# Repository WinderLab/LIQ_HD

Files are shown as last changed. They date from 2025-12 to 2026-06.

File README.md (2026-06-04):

# LIQ-HD - Lick Instance Quantifier Home cage Device 

## UPDATE: 1/19/2024 (Arduino Mega version only)

We have now included the ability to log the lick data by individual bouts! With this setting turned on, each individual bout will be logged with a line in the file with the side the experimental bottle is on (LEFT or RIGHT), a time stamp, the cage number, which bottle was licked (LEFT or RIGHT), bout lick number, bout lick duration, average lick frequency of that bout, and average inter-lick interval of that bout. Note, this setting will not log the total lick number and lick duration (i.e. licks that do not meet bout criteria).

The "log by bout" setting can be turned on using the GUI under "Parameters to log". This setting can be made the default by changing the Arduino code lines 186-187. For example:

bool log_by_bout = true; bool log_by_time = false; //will set the default to "log by bout".

bool log_by_bout = false; bool log_by_time = true; //will set the default to "log by time" (original logging method).

We have also made it easier to change the bout cutoff time (the amount of time during a drinking bout where an animal stops licking before the bout is considered over) by changing the "bout_cutoff" variable on line 185.

We made some minor changes to the capacitive sensor settings that optimizes the baseline tracking for more consistent lick detection.

----------------------------

### Included in this repository:

- Arduino code for LIQ HD running off an Arduino Mega
- Arduino code for LIQ HD running off an Adafruit Grand Central (significantly faster processor speed. NOT FULLY TESTED.)
- 3D models for all required 3D-printed components in various file formats (STL, STEP, SHAPR)
- Step-by-step build instructions and video tutorial can be found on the [Wiki page](https://github.com/WinderLab/LIQ_HD/wiki/LIQ-HD-Step-by-Step-Tutorial)

----------------------------

### Required Arduino Libraries:

- Adafruit_GFX.h
- RTClib.h
- SdFat.h
- Adafruit_MPR121.h
- Adafruit_ILI9341.h
- Adafruit_FT6206.h

---------------------------

### Publication Link : https://www.eneuro.org/content/10/4/ENEURO.0506-22.2023

## Abstract

Investigation of rodent drinking behavior has provided insight into drivers of thirst, circadian rhythms, anhedonia, and drug and ethanol consumption. Traditional methods of recording fluid intake involve periodically weighing bottles, 
which is cumbersome and lacks temporal resolution. Several open-source devices have been designed to improve drink monitoring, particularly for two-bottle choice tasks. However, recent designs are limited by the use of infrared 
photobeam-break sensors and incompatibility with prolonged undisturbed use in ventilated home cages. Beam-break sensors lack accuracy for bout microstructure analysis and are prone to damage from rodents. To address these concerns, we 
designed LIQ HD (Lick Instance Quantifier Home cage Device) with the goal of utilizing capacitive sensors to increase accuracy and analyze lick microstructure, building a device compatible with ventilated vivarium home cages, increasing 
scale with prolonged undisturbed recordings, and creating a design that is easy to build and use with an intuitive touchscreen graphical user interface. The system tracks two-bottle choice licking behavior in up to 18 rodent home cages, 
or 36 single bottles, on a minute-to-minute timescale controlled by a single Arduino microcontroller. The data are logged to a single SD card, allowing for efficient downstream analysis. With sucrose, quinine, and ethanol two-bottle choice 
tasks, we validated that LIQ HD has superior accuracy compared to beam-break sensors. The system measures preference over time and changes in bout microstructure, with undisturbed recordings lasting up to 7 days. All designs and software 
are open-source to allow other researchers to build upon the system and adapt LIQ HD to their animal home cages.

207975271-d024acc4-405c-4381-a1c6-2fc56d0128fb

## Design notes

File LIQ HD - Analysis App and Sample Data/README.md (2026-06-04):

# LIQ HD Analysis 

<p align="center">
LIQ HD Analysis App
</p>

## Included in this folder:
  - LIQ HD Analysis 1.0 Installer for MacOS and Windows
  - Sample LIQ HD Data
    - "LIQ_HD_Sample_Data_Water.CSV" contains data from 16 cages of water two-bottle choice for 1 week. Cages 17 & 18 are empty.
    - "LIQ_HD_Sample_Data_EtOH_Sucrose.CSV" contains data from 8 cages of ethanol two-bottle choice (Cages 1 to 8 - 7% EtOH versus water), and 8 cages of sucrose two-bottle choice (Cages 9 to 16 - 1% Sucrose versus water) for 1 week. Cages 17 & 18 are empty.
  - A How-To Guide can be found on the [Wiki page](https://github.com/WinderLab/LIQ_HD/wiki/LIQ-HD-Analysis-App-Guide) (Coming soon!)

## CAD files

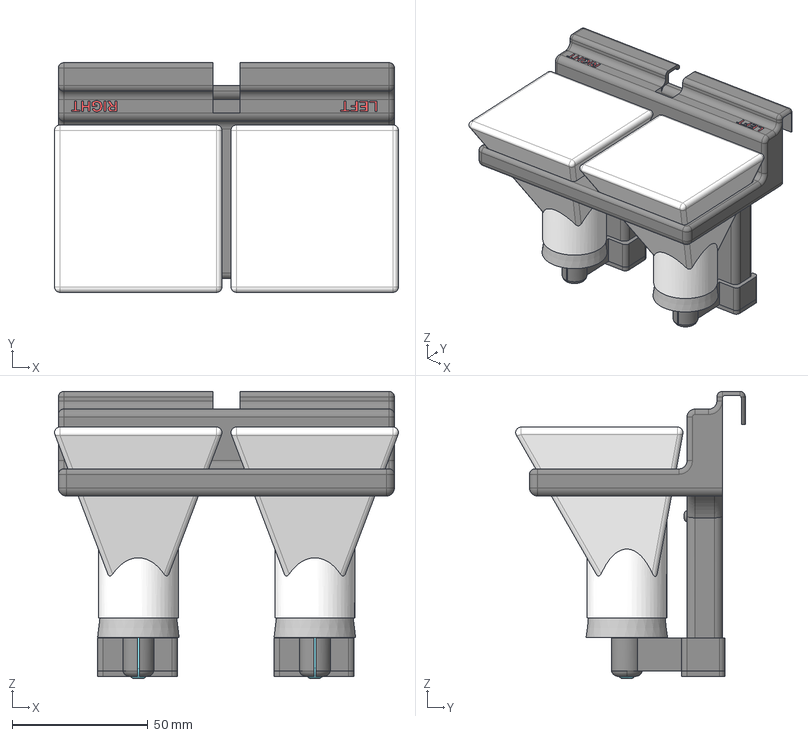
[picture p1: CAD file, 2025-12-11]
LIQ HD - 3D Models github/STEP/LIQ HD - Full model.step
126.5 x 84.5 x 105.6 mm
spouts
stoppers
clips
Text - LEFT/RIGHT
bottles

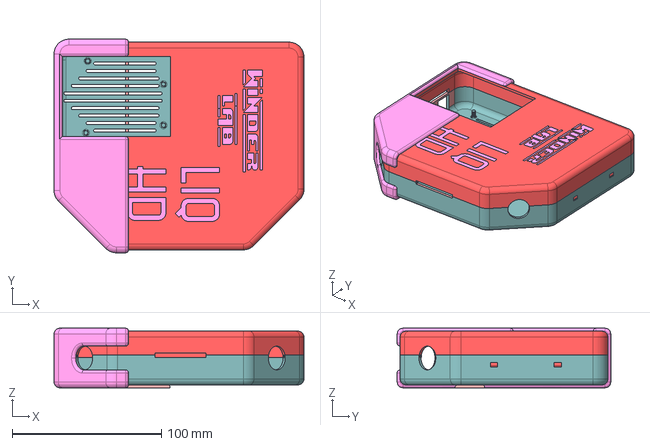
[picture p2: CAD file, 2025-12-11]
LIQ HD - 3D Models github/STEP/LIQ HD - Arduino Box.step
167.8 x 143.4 x 40.0 mm

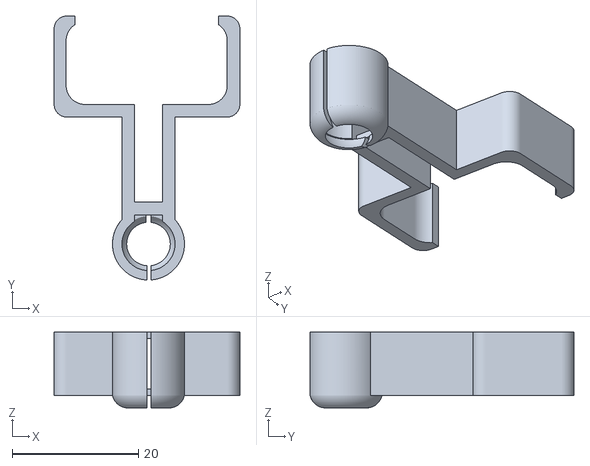
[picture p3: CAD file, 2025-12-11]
LIQ HD - 3D Models github/STL/LIQ HD - Device CLIP 10mm.stl
29.4 x 41.8 x 12.0

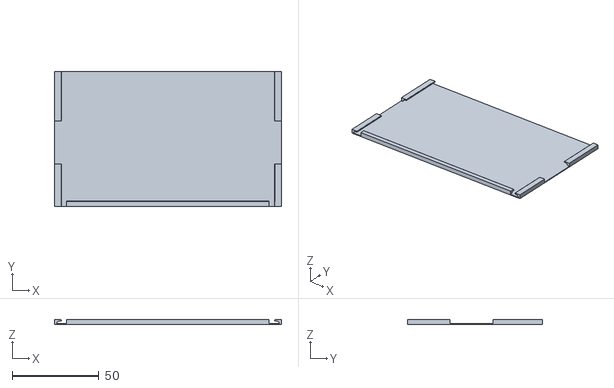
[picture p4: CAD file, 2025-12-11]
LIQ HD - 3D Models github/STL/LIQ HD Card Holder.stl
131.0 x 78.0 x 2.80

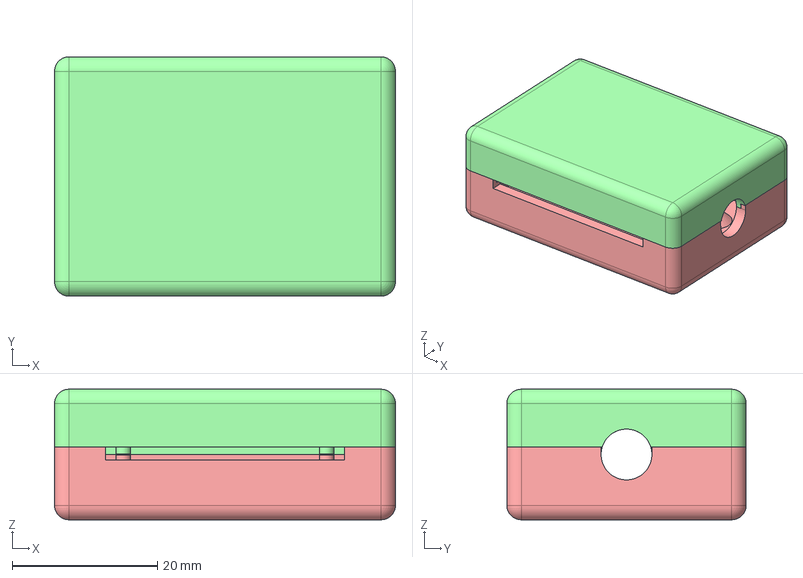
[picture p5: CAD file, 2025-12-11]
LIQ HD - 3D Models github/STEP/LIQ HD - Sensor Box.step
47.0 x 33.0 x 18.0 mm

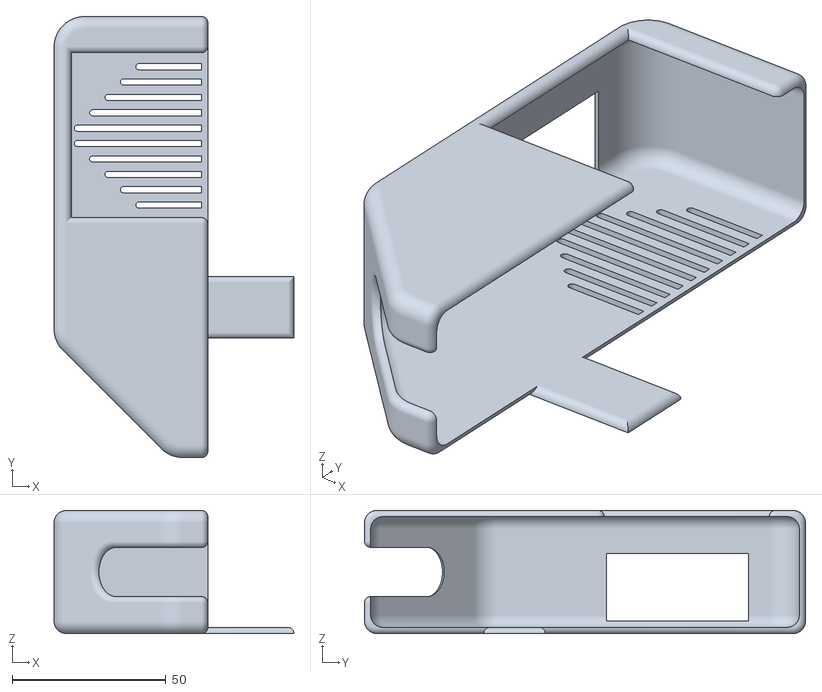
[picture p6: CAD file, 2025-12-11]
LIQ HD - 3D Models github/STL/LIQ HD - Arduino box HOLDER.stl
78.0 x 143.4 x 40.0

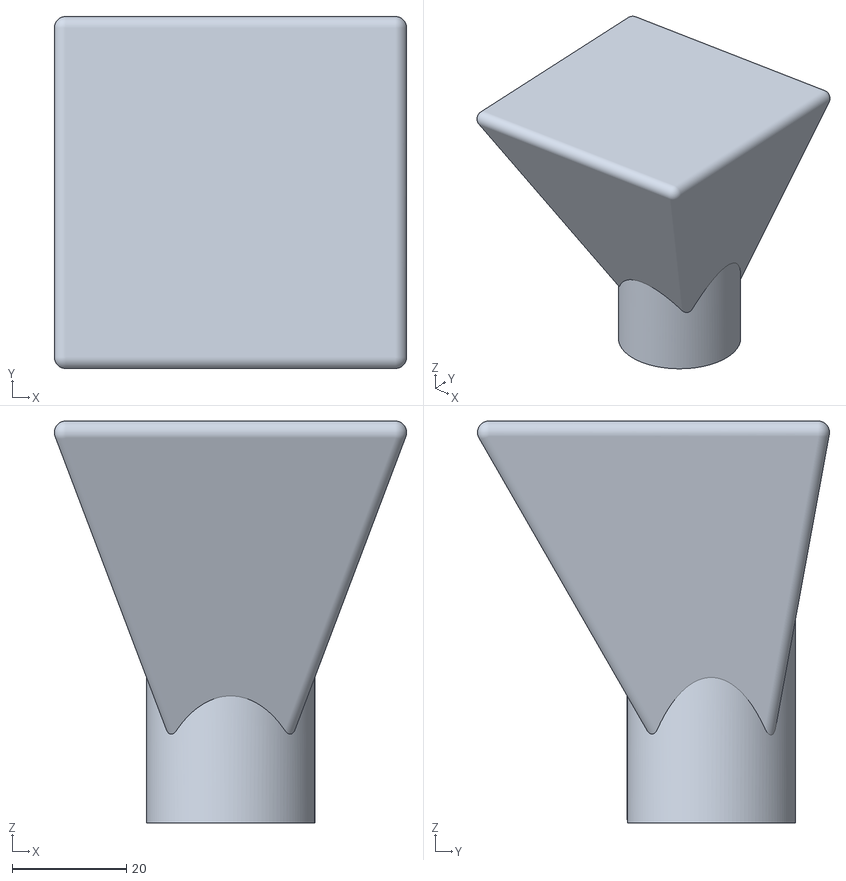
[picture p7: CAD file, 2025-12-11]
LIQ HD - 3D Models github/STL/LIQ HD - Bottle 27mm opening.stl
61.6 x 61.5 x 70.3

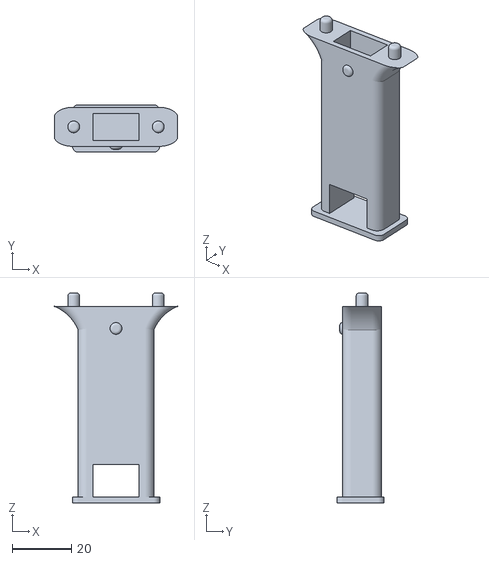
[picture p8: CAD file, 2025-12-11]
LIQ HD - 3D Models github/STL/LIQ HD - Device LEG .stl
41.5 x 16.0 x 70.8

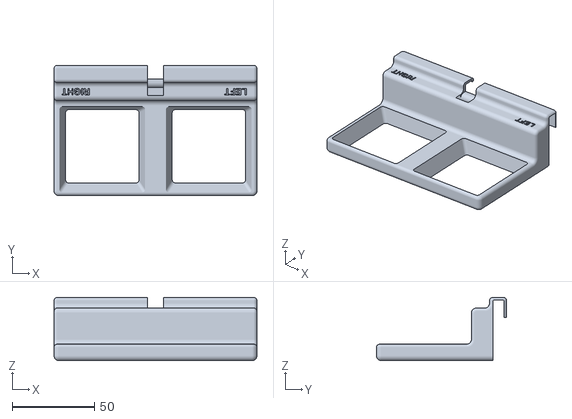
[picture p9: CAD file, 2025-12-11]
LIQ HD - 3D Models github/STL/LIQ HD - Device TOP.stl
123.6 x 79.4 x 38.5

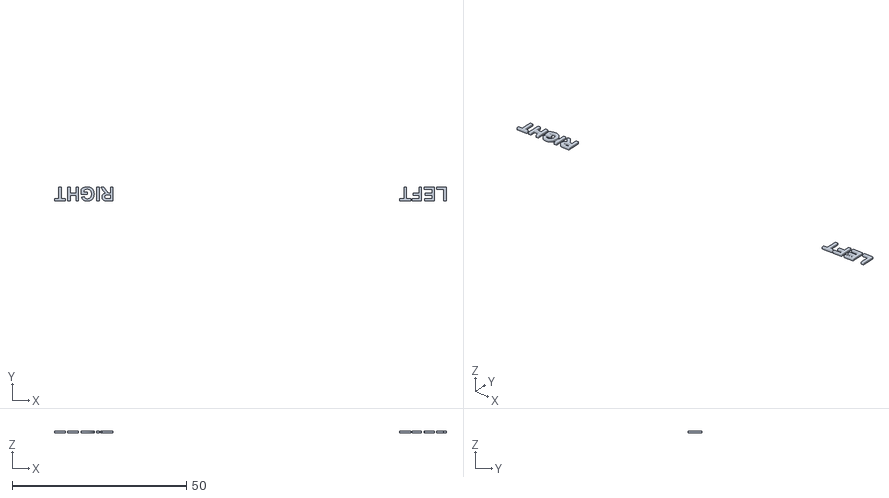
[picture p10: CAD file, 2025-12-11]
LIQ HD - 3D Models github/STL/LIQ HD - Device TEXT.stl
112.5 x 4.14 x 0.6

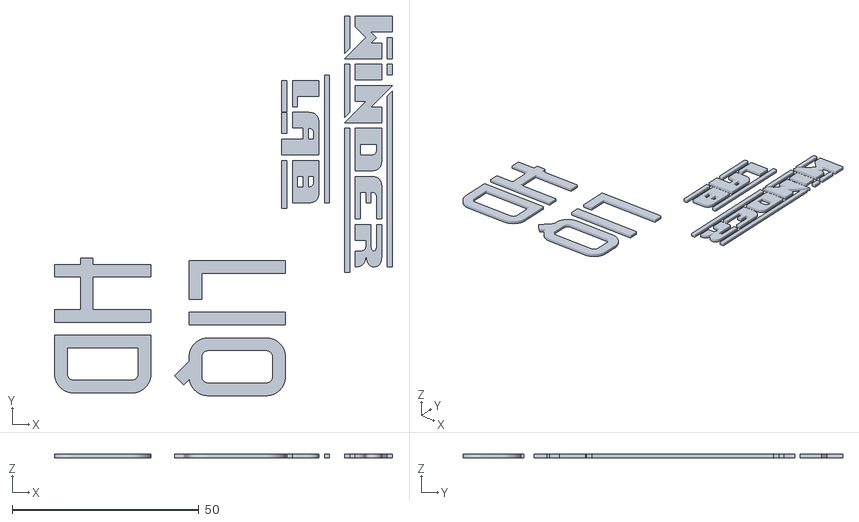
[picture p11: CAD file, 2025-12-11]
LIQ HD - 3D Models github/STL/LIQ HD - Arduino box TEXT.stl
90.5 x 101.6 x 1.00

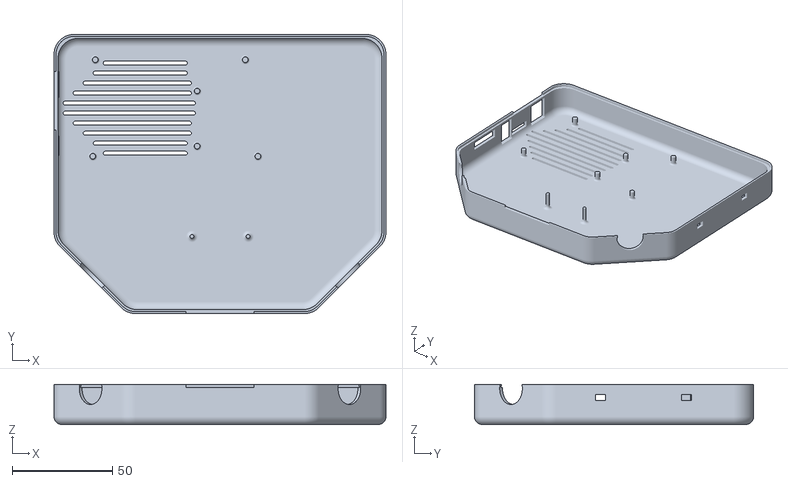
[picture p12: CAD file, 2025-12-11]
LIQ HD - 3D Models github/STL/LIQ HD - Arduino box BOTTOM.stl
165.8 x 139.4 x 20.0

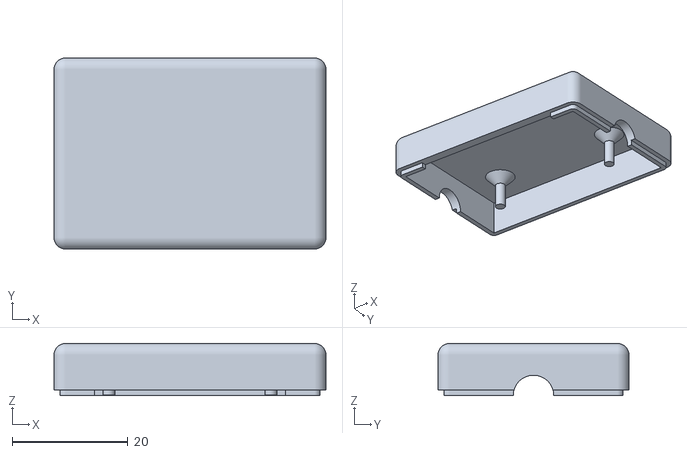
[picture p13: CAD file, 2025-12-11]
LIQ HD - 3D Models github/STL/LIQ HD - Sensor case TOP.stl
47.0 x 33.0 x 9.00

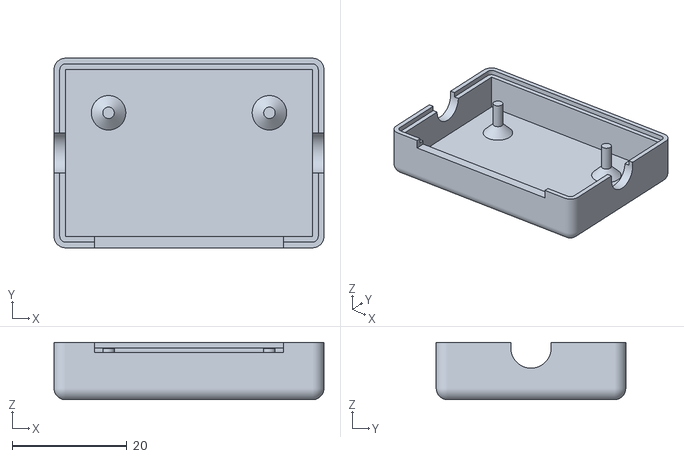
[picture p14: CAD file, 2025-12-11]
LIQ HD - 3D Models github/STL/LIQ HD - Sensor case BOTTOM.stl
47.0 x 33.0 x 10.0

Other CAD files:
LIQ HD - 3D Models github/STL/LIQ HD - Arduino box TOP.stl

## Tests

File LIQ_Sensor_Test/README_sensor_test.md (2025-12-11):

Upload this script to your LIQ HD system and open the serial plotter on the Arduino IDE to visually test lick threshold settings! It is recomended to test only 2-4 sensors because the serial plotter begins to run slowly. If the serial plotter is running too quickly to visualize detected licks, you can slow it down by adding a delay (change "delay_time"). Run this test on a fully built LIQ system in its experimental environment because certain changes, such as wire length, will affect the necessary threshold settings.

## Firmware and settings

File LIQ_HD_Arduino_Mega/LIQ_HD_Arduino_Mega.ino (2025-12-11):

/********************************************************
  LIQ HD
  Written by Nicholas Petersen
  https://github.com/nickpetersen93/LIQ_HD

  January, 2023

  This work includes libraries with the following licensing:
  Adafruit GFX Library - Written by Limor Fried/Ladyada for Adafruit Industries. BSD License
  Adafruit ILI9341 Library - Written by Limor Fried/Ladyada for Adafruit Industries. MIT license. BSD License.
  Adafruit FT6206 Library - Written by Limor Fried/Ladyada for Adafruit Industries. MIT license.
  Adafruit MPR121 Library - Written by Limor Fried/Ladyada for Adafruit Industries. MIT license. BSD License.
  RTCLib Library - Written by JeeLabs. MIT license.
    
  This work is released under This work is licensed under a Creative Commons Attribution-NonCommercial-ShareAlike 4.0 International License:
  https://creativecommons.org/licenses/by-nc-sa/4.0/legalcode

  Copyright (c) 2023 Nicholas Petersen. Creative Commons BY-NC-SA License. Non-Commercial Use Only. 
  Adapter’s License must be a Creative Commons BY-NC-SA or Compatible License. 
  All text above must be included in any redistribution. See LICENSE.md for detailed information.

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
  TO THE EXTENT POSSIBLE, IN NO EVENT WILL THE LICENSOR BE LIABLE TO YOU ON ANY LEGAL THEORY (INCLUDING, 
  WITHOUT LIMITATION, NEGLIGENCE) OR OTHERWISE FOR ANY DIRECT, SPECIAL, INDIRECT, INCIDENTAL, 
  CONSEQUENTIAL, PUNITIVE, EXEMPLARY, OR OTHER LOSSES, COSTS, EXPENSES, OR DAMAGES ARISING OUT OF THIS 
  PUBLIC LICENSE OR USE OF THE LICENSED MATERIAL, EVEN IF THE LICENSOR HAS BEEN ADVISED OF THE 
  POSSIBILITY OF SUCH LOSSES, COSTS, EXPENSES, OR DAMAGES. WHERE A LIMITATION OF LIABILITY IS NOT 
  ALLOWED IN FULL OR IN PART, THIS LIMITATION MAY NOT APPLY TO YOU.
  
  THE DISCLAIMER OF WARRANTIES AND LIMITATION OF LIABILITY PROVIDED ABOVE SHALL BE INTERPRETED IN A 
  MANNER THAT, TO THE EXTENT POSSIBLE, MOST CLOSELY APPROXIMATES AN ABSOLUTE DISCLAIMER AND WAIVER OF 
  ALL LIABILITY.


********************************************************/

#include <Adafruit_GFX.h>
#include <SPI.h>
#include <Wire.h>
#include <SD.h>
#include "RTClib.h"
#include "Adafruit_MPR121.h"
#include <Adafruit_ILI9341.h>
#include <Adafruit_FT6206.h>
#include <math.h>
#include <Fonts/FreeSans9pt7b.h>
#include <Fonts/FreeSans12pt7b.h>
#include <Fonts/FreeSans18pt7b.h>
#include <Fonts/FreeSansBold9pt7b.h>
#include <Fonts/FreeSansBold12pt7b.h>
#include <Fonts/FreeSansBold18pt7b.h>
#include <Fonts/FreeSansBold24pt7b.h>


//#define DEBUG //uncomment to turn on debug mode, prints info to Serial Monitor

#ifdef DEBUG
#define DEBUG_PRINT(x) Serial.print(x)
#define DEBUG_PRINTDEC(x) Serial.print(x, DEC)
#define DEBUG_PRINTLN(x) Serial.println(x)
#else
#define DEBUG_PRINT(x)
#define DEBUG_PRINTDEC(x)
#define DEBUG_PRINTLN(x)
#endif

// The FT6206 uses hardware I2C on the shield
Adafruit_FT6206 ts = Adafruit_FT6206();

// The display also uses hardware SPI, plus #9 & #10
#define TFT_CS 10
#define TFT_DC 9
Adafruit_ILI9341 tft = Adafruit_ILI9341(TFT_CS, TFT_DC);

RTC_PCF8523 rtc;           // define the Real Time Clock object
const int chipSelect = 7;  // for the data logging shield, changed from digital pin 10
#define redLEDpin 13
DateTime now;

//capacitive touch device
#ifndef _BV
#define _BV(bit) (1 << (bit))
#endif

// You can have up to 4 on one i2c bus but one is enough for testing!
Adafruit_MPR121 cap = Adafruit_MPR121();
Adafruit_MPR121 cap2 = Adafruit_MPR121();
Adafruit_MPR121 cap3 = Adafruit_MPR121();

// Keeps track of the last pins touched so we know when buttons are 'released'
uint16_t lasttouched1 = 0;
uint16_t currtouched1 = 0;
uint16_t lasttouched2 = 0;
uint16_t currtouched2 = 0;
uint16_t lasttouched3 = 0;
uint16_t currtouched3 = 0;

File logfile;  // the logging file
char filename[] = "00000000.CSV";

TS_Point p;
extern uint8_t welcome_logo[];
extern uint8_t main_logo[];
extern uint8_t settings_icon[];
extern uint8_t settings_icon2[];
unsigned long startmillis;
String E_side = "RIGHT";
String display_page = "main";
bool show_time = true;
bool eject_button;
int LOG_COUNTER;
int SYNC_COUNTER;
unsigned long currentMillis;
unsigned long previousMillis;
int syncTime;
int min_now;
int prev_min;
int curr_min;
int hour_now;
bool refresh_page = true;
int timeouts = 0;
bool ok;
int default_lights_on;
int default_lights_off;
int default_touch_threshold;
int default_release_threshold;
int default_LOG_INTERVAL;
int dafault_SYNC_INTERVAL;
bool default_auto_cal;
int default_auto_cal_time;
int default_auto_cal_sec_since_last_lick;
bool auto_cal_flag = true;
unsigned long cal_timer;
String logging[8];
bool log_LN = true;
bool log_LD = true;
bool log_BN = true;
bool log_BD = true;
bool log_BLN = true;
bool log_BLD = true;
bool recording = false;
String licked_bottle;

//enough for 18 cages, 2 lickometers per cage
unsigned long LickDuration[36];
unsigned long LickNumber[36];
unsigned long BoutNumber[36];
unsigned long BoutDuration[36];
unsigned long BoutLickNumber[36];
unsigned long BoutLickDuration[36];
unsigned long BoutLickDuration_bytime[36];
float LickFrequency[36];
float ILI[36];
unsigned long Elapsedtime[36];
unsigned long total_LN[36];
int lick_bout_countdown[36];
unsigned long bout_timer[36];
unsigned long bout_start_timer[36];
bool in_bout[36];
bool licking[36];
unsigned long time_now[36];
unsigned long last_lick_time[36];

// how many minutes between grabbing data and logging it.
int LOG_INTERVAL = 1;  // IN MINUTES! between entries (reduce to take more/faster data)
// how many milliseconds before writing the logged data permanently to disk
int SYNC_INTERVAL = 10;                   // IN MINUTES! between calls to flush() - to write data to the card
unsigned long emergency_counter = 60050;  //1 minute +50ms

// Typically touch threshold > release threshold for debouncing
// Decrease value to increase sensitivity
int touch_threshold = 2;    //default = 12
int release_threshold = 0;  //default = 6
//int current = 50;           //Range of 1-63uA //ignore for now
int debounce = 0;           //range 0-7
bool auto_cal = true;       //flag to turn on daily auto calibration by defaults
int auto_cal_time = 7;      //hour in the day when auto cal will occur (best in light cycle when animals less active)
int auto_cal_sec_since_last_lick = 60;  //Time in seconds of inactivity before auto cal will happen
int bout_cutoff = 3000;     //bout cut off time in milliseconds 
bool log_by_bout = false;    //flag to turn on "log by bout" mode by default, ONLY ONE SHOULD BE TRUE
bool log_by_time = true;   //flag to turn on "log by time" mode by default, ONLY ONE SHOULD BE TRUE

int lights_on = 6;    //time of day (24hr time) housing lights turn ON
int lights_off = 18;  //time of day (24hr time) houseing lights turn OFF

//==========================================================================================

void setup() {
#ifdef DEBUG
  Serial.begin(115200);
#endif

  pinMode(5, OUTPUT);  // set screen brightness pin as output
  analogWrite(5, 255);

  set_defaults();  //save coded settings as the default settings

  start_display();  //initialize display

  start_rtc();  //iniitialize rtc

  WelcomeScreen();  //display welcome screen at startup

  set_brightness();  //set screen brightness depending on light cycle
}

//==========================================================================================

void loop() {

  main_menu_page();

  recording_page();

  pause_page();

  SD_error_page();

  settings_page();

  error_page();
}
